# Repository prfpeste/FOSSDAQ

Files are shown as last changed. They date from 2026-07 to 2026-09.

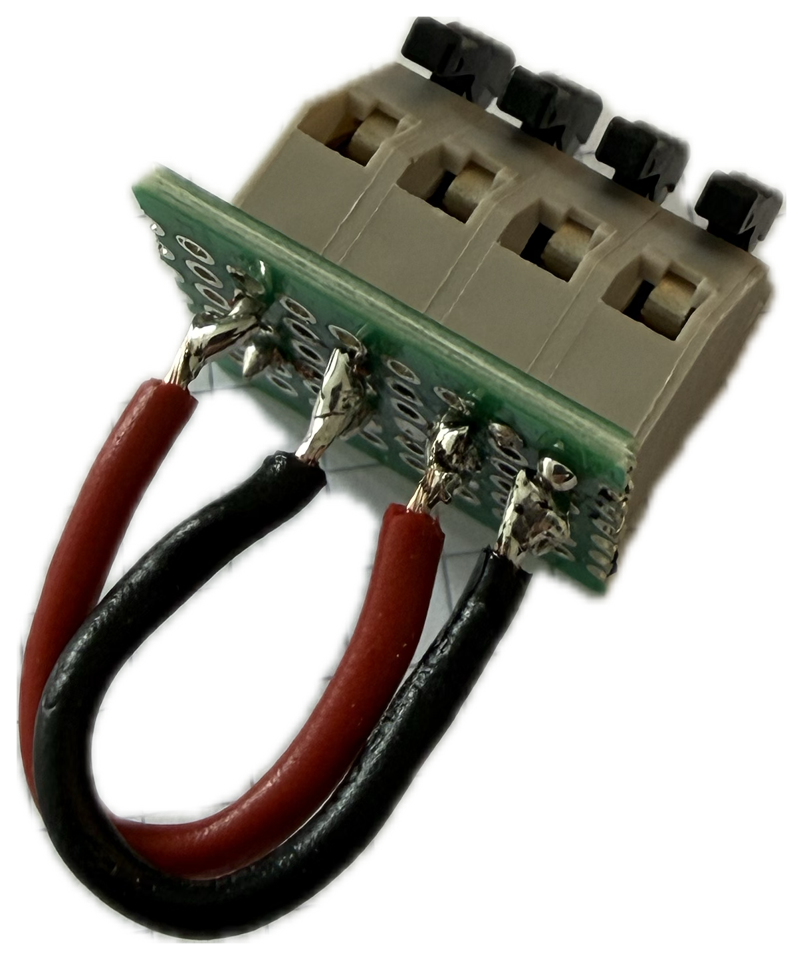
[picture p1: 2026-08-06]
modules/ai-8x-0to3v3/images/bus-terminal-solder-side.png

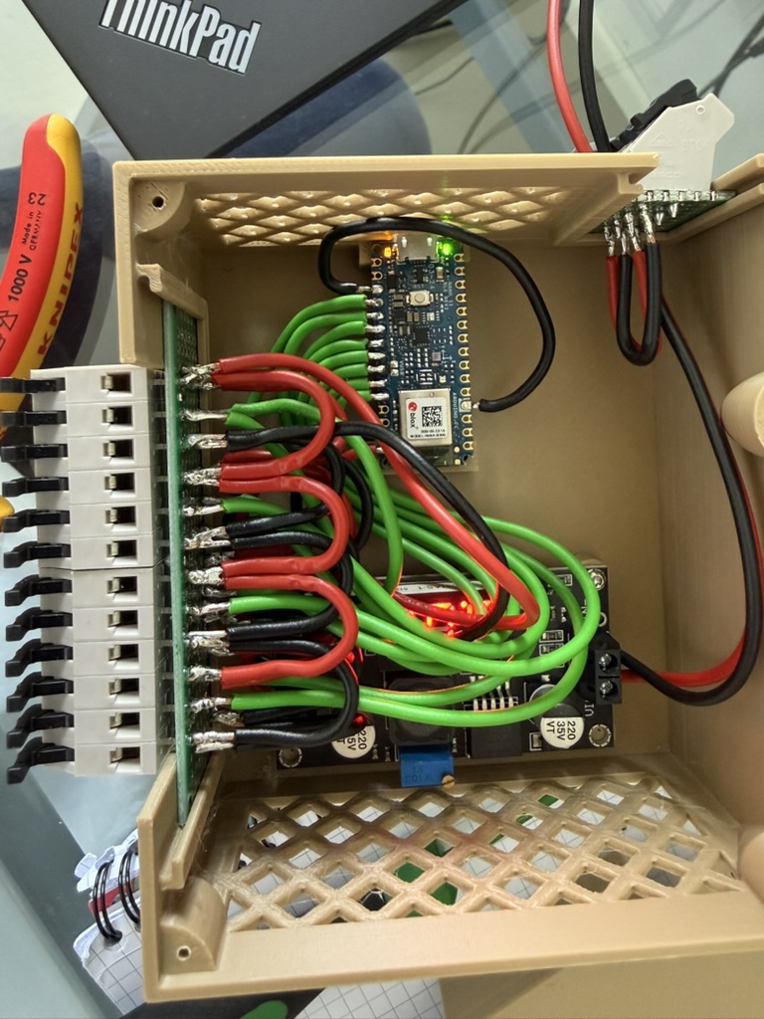
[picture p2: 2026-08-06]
modules/ai-8x-0to3v3/images/assembled-open-top.jpeg

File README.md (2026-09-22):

# FOSSDAQ
Free and Open Source Software (and hardware) for Data Acquisition 

## Project aim

The system was deliberately not designed as a fully industrialised measurement system, but rather as an easily replicable, open and cost-effective platform for use in teaching and laboratories. The focus is on low material costs, the use of readily available standard components, an easily comprehensible circuit topology, and the ability for students to assemble and adapt modules themselves, and to replace them with minimal effort in the event of a fault. Additional measures to increase robustness, EMC immunity or comprehensive fault protection were therefore only taken into account to the extent that they are necessary for the intended use in supervised laboratory environments. For applications in harsh industrial environments or with increased requirements for reliability and immunity to interference, more extensive protection and interface circuitry is required.

## Repository structure

The FOSSDAQ repository is organised by purpose and module:

- `README.md`  
  Entry point to the project: overview, goals, modules, and links.

- `LICENSE-*`  
  License files for hardware, software, and documentation.

- `docs/`  
  System-level documentation, background information, contribution guidelines, and general design notes that are not tied to a single module.

- `common/`  
  Shared specifications and resources used across multiple modules, e.g. power bus concept, mechanical interface, naming conventions, and templates.

- `modules/`  
  All hardware modules of the FOSSDAQ system.  
  Each subdirectory (e.g. `pi-base/`, `ai-8x-0to3v3/`) contains everything needed for that module:
  - `hardware/` – CAD, KiCad, manufacturing files  
  - `firmware/` – module-specific microcontroller code  
  - `docs/` – build and test notes  
  - `bom/` – parts list  
  - `images/` – photos and renders  

- `software/`  
  System-level software components and tooling.

  - `software/nodered/`  
    Node-RED based control and visualisation:
    - `README.md` – how to install and use the flows with FOSSDAQ  
    - `flows/` – exported Node-RED flows  
    - `nodes/` – custom nodes or subflows (if any)  
    - `examples/` – example setups for specific modules

## Contributors

FOSSDAQ is developed as an open modular measurement system in the context of student projects and teaching.

#### Project lead and supervision
- Prof. Dr. Peter Stein (HTWG Konstanz - Maschinenbau)

#### Core contributors
- Jürgen Altemeier (HTWG Konstanz - Maschinenbau - basic concept and first modules - 2026)
- Patrick Uitz (HTWG Konstanz - Maschinenbau - basic concept and first modules - 2026)

#### Further module contributors
- To be added as new modules are published

## Related Projects

- [FOSSTHERM](https://github.com/prfpeste/FOSSTHERM) – Free and Open Source Thermal Experiments

## License

FOSSDAQ uses different licenses for different parts of the project:

- **Hardware design files** in `hardware/` are licensed under **CERN-OHL-W-2.0**.  
  See `LICENSE-HARDWARE - CERN-OHL-W-2.0`.

- **Firmware and software** in `firmware/` and `software/` are licensed under **GPL-3.0-or-later**.  
  See `LICENSE-SOFTWARE - GPL-3.0`.

- **Documentation** in `docs/` is licensed under **CC-BY-SA-4.0**.  
  See `LICENSE-DOCS - CC-BY-SA-4.0`.

Unless explicitly stated otherwise, new files should follow the license of their parent directory.

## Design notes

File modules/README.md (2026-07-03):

## Available modules

- `pi-base` – central Raspberry Pi carrier and rail module
- `ai-8x-0to3v3` – 8-channel analog input card for 5 V sensors with 0–3.3 V output

## License

Hardware files in this module are licensed under CERN-OHL-W-2.0.  
Firmware/software is licensed under GPL-3.0.  
Documentation is licensed under CC-BY-SA-4.0.

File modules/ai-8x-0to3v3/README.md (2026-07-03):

# ai-8x-0to3v3

8-channel analog input module for the FOSSDAQ system.

This module is designed for sensors with 5 V supply and analog output signals in the range of 0–3.3 V. It is based on an Arduino Nano and communicates with the Raspberry Pi via USB.

## Status

- Development status: prototype
- Hardware version: v1.0
- Firmware status: defined separately
- Last updated: June 19, 2026

## Purpose

The `ai-8x-0to3v3` module is the first fully developed analog measurement card of the FOSSDAQ system. It is intended for simple and low-cost acquisition of analog sensor signals in educational and laboratory setups.

## Features

- 8 analog input channels
- Designed for 5 V powered sensors with 0–3.3 V signal output
- Based on Arduino Nano 33 BLE Rev2 or Arduino Nano R4
- 12-bit ADC via analog pins A0–A7
- Local 5 V generation from shared 24 V DC bus
- USB connection to Raspberry Pi for data only
- 3D-printed enclosure for TS-35 DIN rail mounting
- Spring terminal connections for sensor wiring

## Directory structure

- `hardware/` – KiCad files, CAD files, exported manufacturing files
- `firmware/` – microcontroller code for this module
- `docs/` – build notes, technical documentation, test instructions
- `bom/` – parts list for the module
- `images/` – photos and renders

**BOM** stands for **Bill of Materials** and refers to the module's parts list.

## Build and assembly

1. Print the enclosure parts.
2. Prepare the perfboard sections.
3. Assemble the 24 V input and pass-through terminal block.
4. Build the sensor terminal carrier board.
5. Solder the required connections to the Arduino Nano.
6. Connect the LM2596S power converter.
7. Install the electronics into the enclosure.
8. Connect the module to the Raspberry Pi via USB.
9. Perform the checks described in `docs/`.

## Interfaces

### Power
- Bus input: nominal 24 V DC
- Converter input range: 10–35 V DC (LM2596S module)
- Local logic/sensor supply: 5 V generated locally
- Shared system ground: yes
- Galvanic isolation: no

### Data
- Interface to host: USB 2.0
- Connector: Micro-USB-B on Arduino Nano 33 BLE Rev2
- USB used as: data path only

### Signals
- Channel count: 8
- Input pins: A0–A7
- Signal range: 0–3.3 V
- Typical sensor type: pressure or flow sensors with active 5 V supply

### Mechanics
- Mounting: TS-35 DIN rail
- Enclosure: 3D-printed
- Front connections: spring terminal blocks

## Main components

- Arduino Nano 33 BLE Rev2
- Optional alternative: Arduino Nano R4
- LM2596S DC/DC converter module
- AST 025-06 spring terminal blocks for sensor connections
- AST 025-04 spring terminal blocks for 24 V bus input/pass-through
- Double-sided perfboard
- 3D-printed enclosure parts

## Files

Important project files for this module include:
- FreeCAD files for enclosure, cover, DIN rail latch, and assembly
- KiCad schematic page for the analog input card
- BOM for components and wiring
- Build and test documentation

## Intended use and limitations

This module is intended for educational, demonstrator, and laboratory use in controlled environments. The design prioritizes simplicity, low cost, and ease of reproduction over maximum electrical robustness. The module uses a shared ground and does not include galvanic isolation. Additional protection, filtering, and EMC measures may be required for use in harsher environments or outside supervised lab settings.

## Contributors

- Jürgen Altemeier
- Patrick Uitz

## License

Hardware design files in this module are licensed under **CERN-OHL-W-2.0**.  
Firmware and software are licensed under **GPL-3.0-or-later**.  
Documentation is licensed under **CC-BY-SA-4.0**.

See the repository root license files for details.

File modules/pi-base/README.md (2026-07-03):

# pi-base

Central Raspberry Pi rail module for the FOSSDAQ system.

This module hosts the Raspberry Pi 5 as the central unit of the system, provides integration on a TS-35 DIN rail, converts the shared 24 V bus to 5 V locally, and serves as the data hub for connected measurement cards via USB.

## Status

- Development status: prototype
- Hardware version: v1.0
- Firmware/software status: external software interface defined outside this module
- Last updated: June 19, 2026

## Purpose

The `pi-base` module is the central master unit of the FOSSDAQ platform. It is intended for educational and laboratory use and provides the mechanical, electrical, and communication backbone for modular measurement cards.

## Features

- Raspberry Pi 5 based central unit
- Mounting on TS-35 DIN rail
- Local 5 V generation from shared 24 V DC bus
- 3D-printed enclosure with side cover and rail latch
- Front access to USB and Ethernet ports
- Active cooling via Raspberry Pi active cooler
- Designed for open-source reproduction and modification

## Directory structure

- `hardware/` – KiCad files, CAD files, exported manufacturing files
- `firmware/` – optional scripts or module-specific setup files
- `docs/` – build notes, technical documentation, test instructions
- `bom/` – parts list for the module
- `images/` – photos and renders

**BOM** stands for **Bill of Materials** and refers to the module's parts list.

## Build and assembly

1. Print the enclosure parts.
2. Assemble the DIN rail latch and side cover.
3. Install the Raspberry Pi 5 and active cooler.
4. Build the 24 V input and pass-through terminal assembly.
5. Connect the 24 V input to the LM2596S step-down converter.
6. Feed the generated 5 V to the Raspberry Pi.
7. Close the enclosure and perform the checks described in `docs/`.

## Interfaces

### Power
- Bus input: 24 V DC ± 5 %
- Local logic voltage: 5 V generated locally from the 24 V bus
- Shared system ground: yes

### Data
- Host system: Raspberry Pi 5
- USB used as: data connection to measurement cards
- Ethernet: available on front side
- USB power distribution to cards: not intended

### Mechanics
- Mounting: TS-35 DIN rail
- Enclosure: 3D-printed
- Cooling: active CPU cooler, enclosure ventilation openings

## Main components

- Raspberry Pi 5 (8 GB RAM recommended)
- Official Raspberry Pi active cooler
- Optional RTC battery
- LM2596S DC/DC converter module
- AST 025-04 spring terminal block for 24 V input and pass-through
- 3D-printed enclosure parts

## Files

Important project files for this module include:
- FreeCAD files for enclosure, cover, DIN rail latch, and assembly
- 3MF export files for printing
- KiCad schematic page for the 24 V supply concept
- Module-specific BOM and build documentation

## Intended use and limitations

This module is intended for supervised educational and laboratory environments. The design prioritizes simplicity, low cost, accessibility, and ease of reproduction over maximum ruggedness. Additional protection, isolation, or EMC measures may be required for use in industrial or electrically harsh environments.

## Contributors

- Jürgen Altemeier
- Patrick Uitz

## License

Hardware design files in this module are licensed under **CERN-OHL-W-2.0**.  
Firmware and software are licensed under **GPL-3.0-or-later**.  
Documentation is licensed under **CC-BY-SA-4.0**.

See the repository root license files for details.

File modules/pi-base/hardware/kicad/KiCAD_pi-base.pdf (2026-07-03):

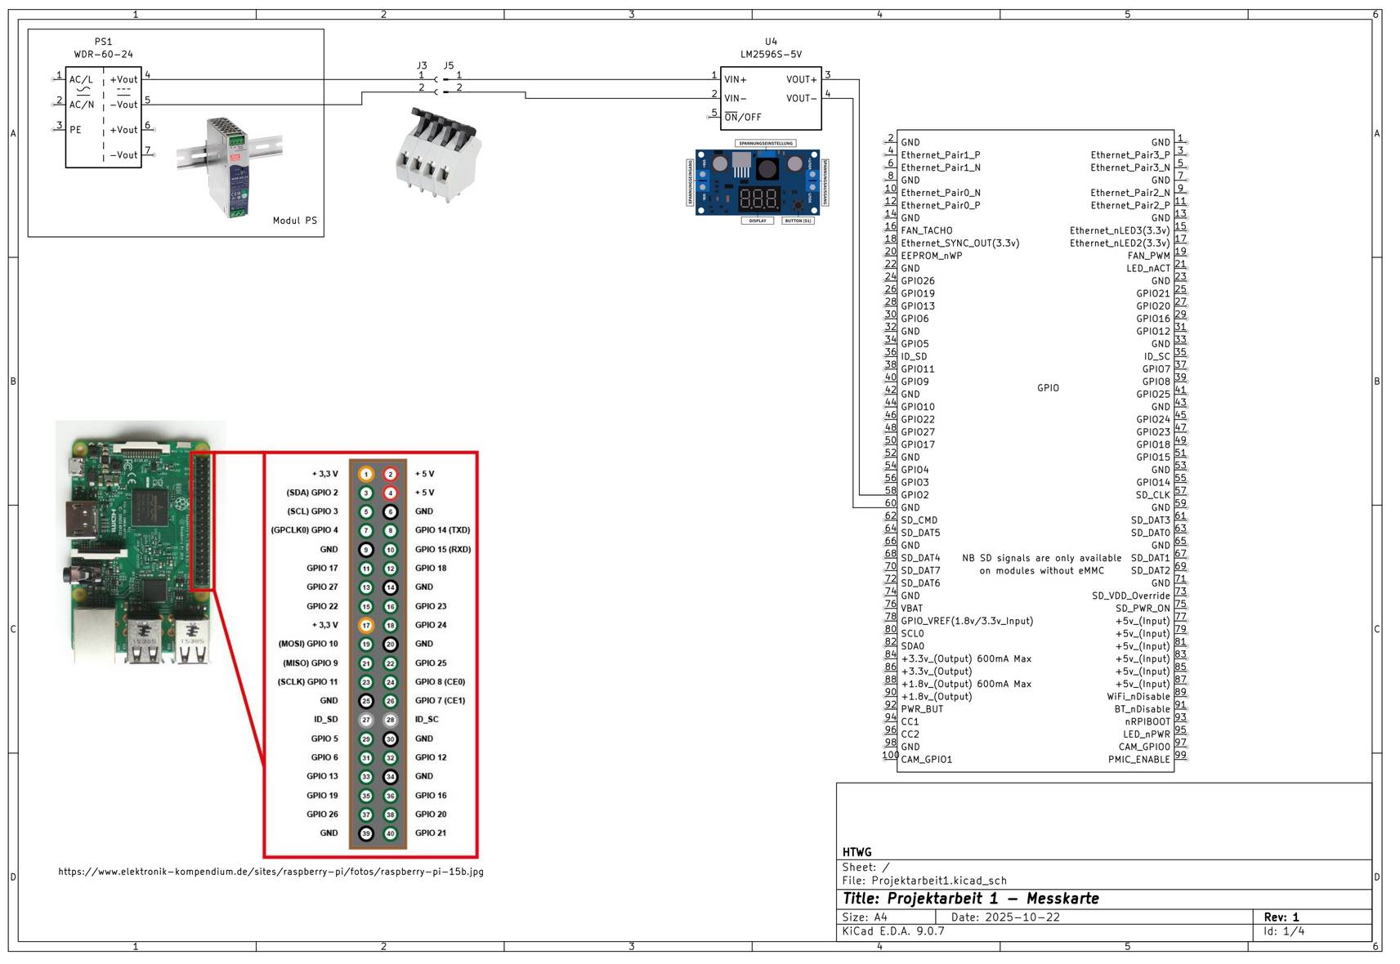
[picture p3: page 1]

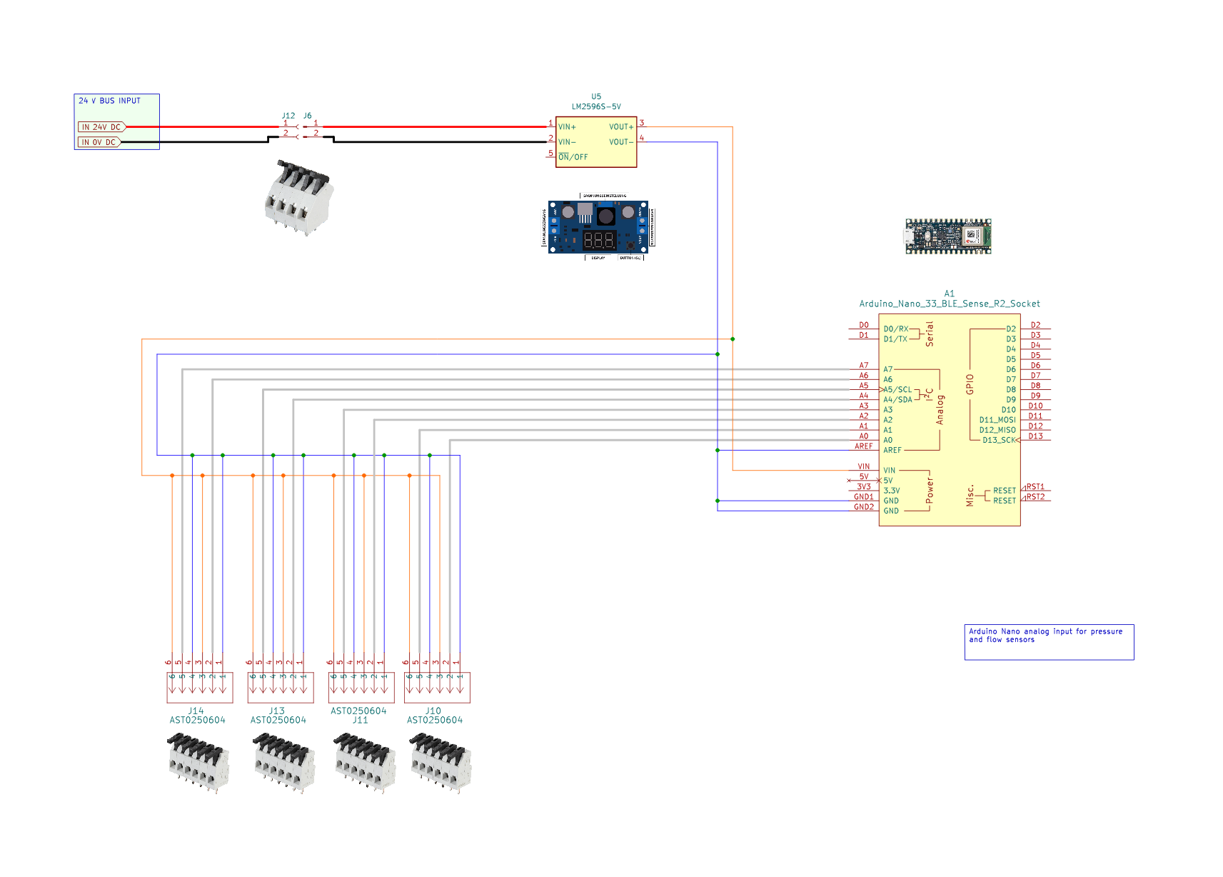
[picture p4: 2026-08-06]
modules/ai-8x-0to3v3/images/schematic-ai-8x-0to3v3.png

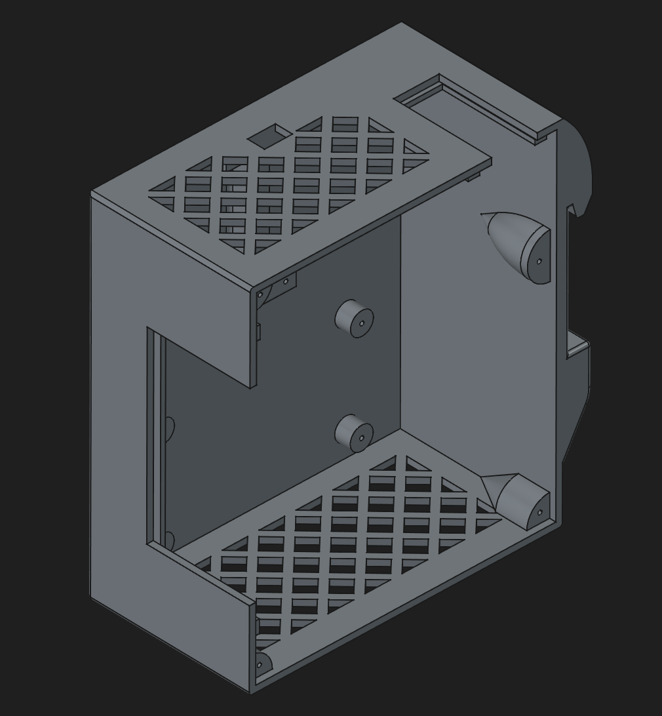
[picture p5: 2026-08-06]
modules/ai-8x-0to3v3/images/enclosure-iso-open.png

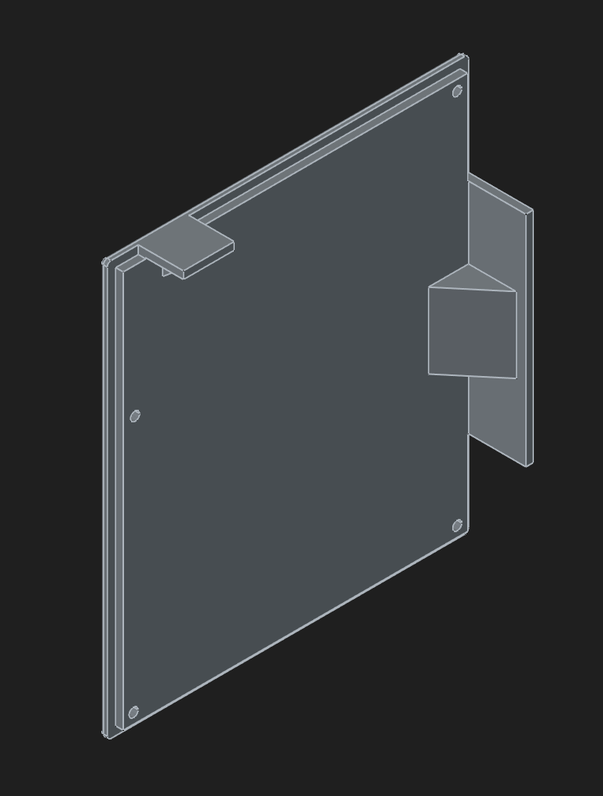
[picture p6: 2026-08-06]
modules/ai-8x-0to3v3/images/cover.png

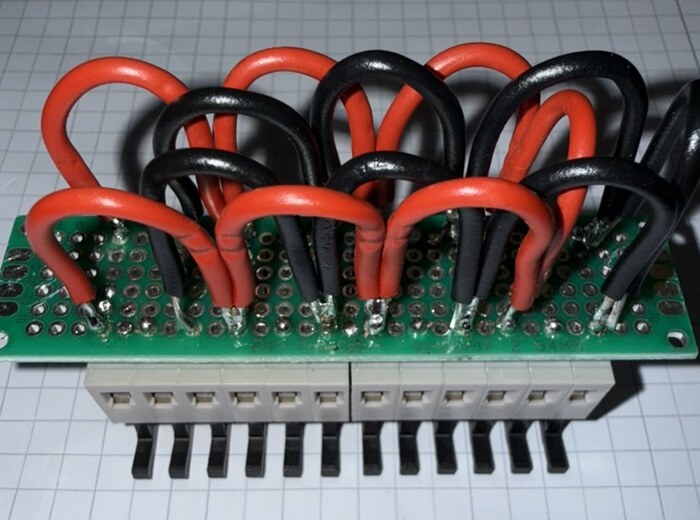
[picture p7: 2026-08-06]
modules/ai-8x-0to3v3/images/sensor-terminals-supply-rails.jpeg

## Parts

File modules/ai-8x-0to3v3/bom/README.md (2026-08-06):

# BOM
- 1 x Arduino Nano 33 BLE Rev2 - ARD NANO 33BLE2
- 2 x Breadboard (perfboard), double-sided, 80 x 20 mm - LR-DS-28 (1x sensor terminal carrier, 1x strip for the 24 V bus terminal)
- 1 x DC/DC step-down converter LM2596S with display (Joy-IT) - DEBO DCDC DOWN 5
- 4 x Spring loaded terminal, 6-pin, 5 mm pin spacing - AST 025-06 (sensor terminals)
- 1 x Spring loaded terminal, 4-pin, 5 mm pin spacing - AST 025-04 (24 V bus input + pass-through)
- 1 x USB-A to Micro-USB-B data cable, 1 m (USB-C cable for the Nano R4)
- approx. 1 m stranded wire H05V-K 1 x 0.75 mm², red (+24 V / +5 V)
- approx. 1 m stranded wire H05V-K 1 x 0.75 mm², black (0 V)
- approx. 2 m stranded wire H05V-K 1 x 0.75 mm², green (sensor signals A0-A7)
- 3D printing PLA filament
- min. 15 x self-tapping Torx screws M2.3 x 6 mm (assortment set) - B0G6YNG9CW

Notes: Part designations follow the supplier product titles, so
they can be found directly together with the order codes. Wire colors are
freely selectable - recommended: red for +24 V/+5 V, black for 0 V and
green for signal wires (consistent across the whole system).

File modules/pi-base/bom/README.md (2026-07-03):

#BOM
- 1 x Raspberry Pi 5B
- 1 x Lüfter für Raspberry Pi 5 - RASP ACTIVE COOL
- 1 x RTC Batterie - RASP RTC BAT
- 1 x Lochrasterplatine 80 x 20 mm - LR-DS-28
- 1 x DC/DC converters - DEBO DCDC DOWN 5
- 1 x Federkraftklemme - AST 025-04 (4-pol., RM 5 mm)
- 3D Druck PLA Filament
- 12 x Schrauben M2,3 x 6 mm selbstschneidend (Torx-Set) -B0G6YNG9CW

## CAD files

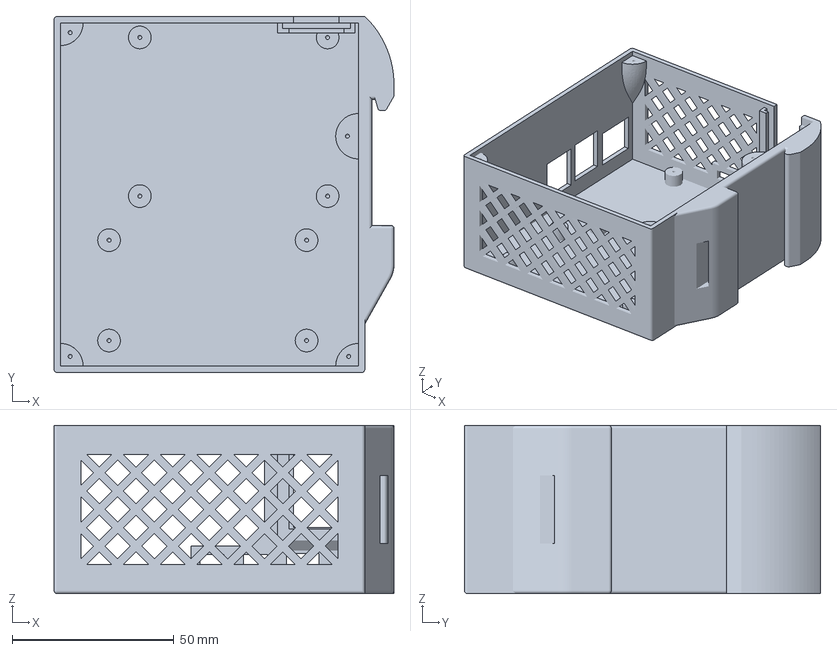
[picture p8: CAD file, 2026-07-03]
modules/pi-base/hardware/cad/End_Gehäuse+Slate-Assembly.3mf
105.0 x 110.0 x 52.0 mm

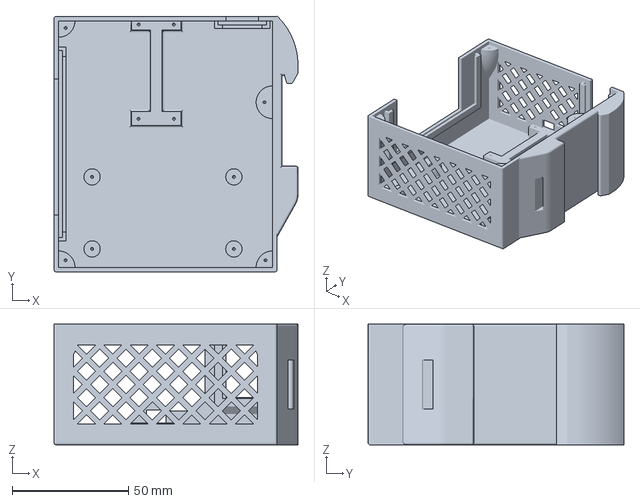
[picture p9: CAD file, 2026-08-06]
modules/ai-8x-0to3v3/hardware/cad/AI-Gehaeuse+Slate-Assembly.3mf
105.0 x 110.1 x 52.0 mm

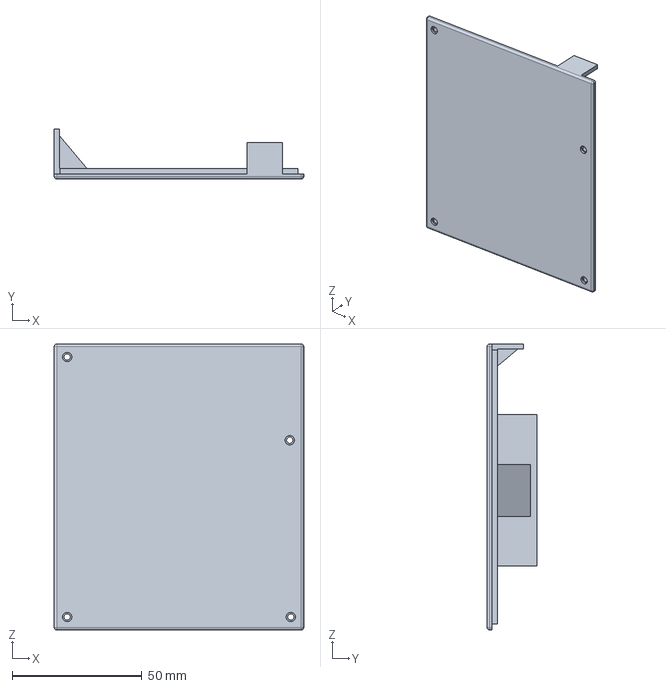
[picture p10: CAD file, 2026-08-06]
modules/ai-8x-0to3v3/hardware/cad/AI-Deckel_v2.FCStd
96.0 x 19.3 x 110.0 mm

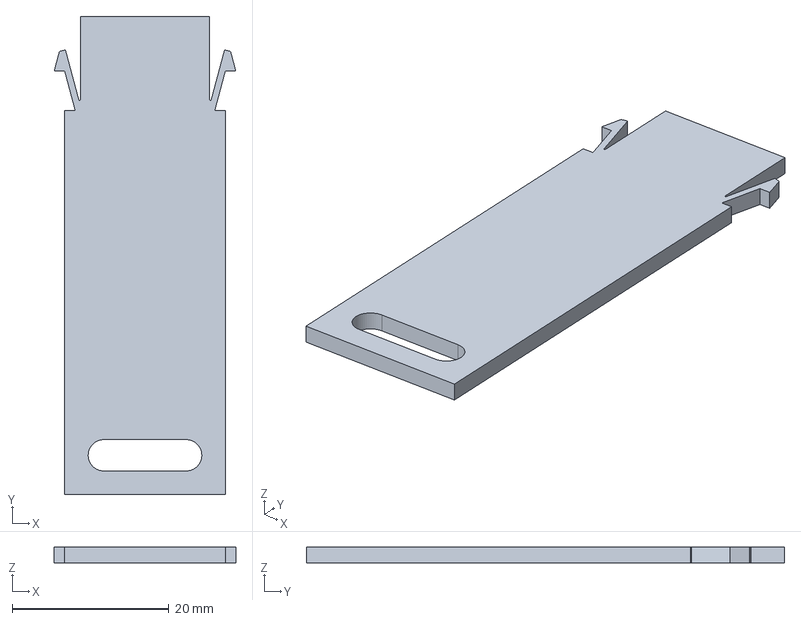
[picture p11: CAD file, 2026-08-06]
modules/ai-8x-0to3v3/hardware/cad/AI-Stift.FCStd
23.2 x 61.0 x 2.00 mm

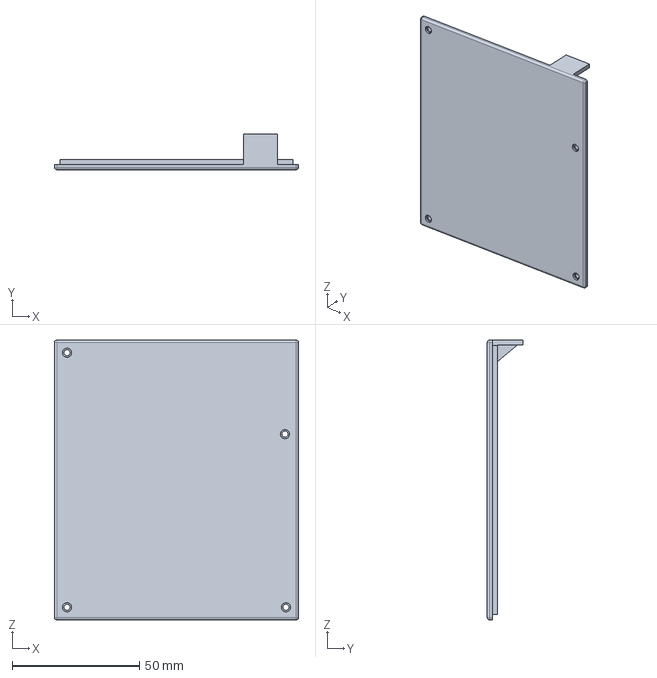
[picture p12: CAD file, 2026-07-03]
modules/pi-base/hardware/cad/End_Deckel.FCStd
96.0 x 14.0 x 110.0 mm

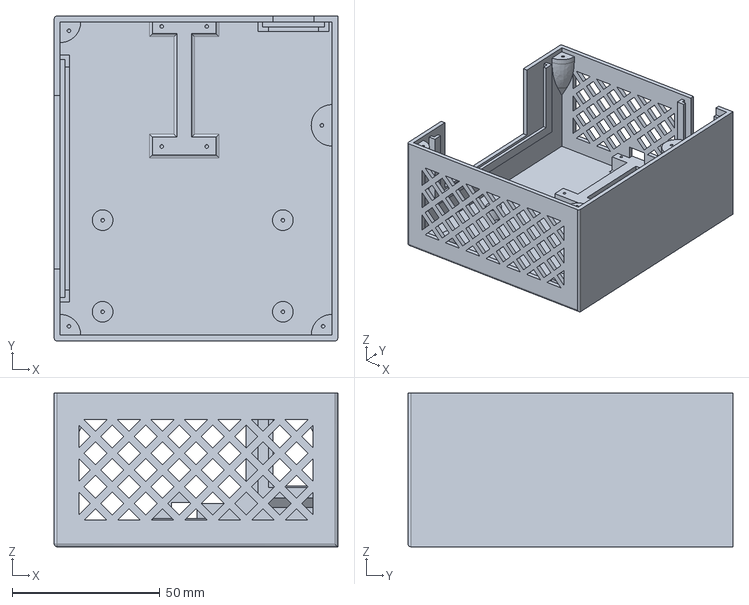
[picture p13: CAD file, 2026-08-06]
modules/ai-8x-0to3v3/hardware/cad/AI-Gehaeuse.FCStd
96.0 x 110.0 x 52.0 mm

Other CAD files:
modules/pi-base/hardware/cad/End_Deckel-Body.3mf
modules/ai-8x-0to3v3/hardware/cad/AI-Deckel_v2-Body.3mf
modules/pi-base/hardware/cad/End_Gehäuse+Slate.FCStd
modules/pi-base/hardware/cad/End_Stift.FCStd
modules/ai-8x-0to3v3/hardware/cad/AI-Stift-Body.3mf
modules/pi-base/hardware/cad/End_Stift-Body.3mf
modules/ai-8x-0to3v3/hardware/cad/AI-Deckel_v2-Body.stl
modules/ai-8x-0to3v3/hardware/cad/AI-Gehaeuse+Slate-Assembly.stl
modules/ai-8x-0to3v3/hardware/cad/AI-Stift-Body.stl

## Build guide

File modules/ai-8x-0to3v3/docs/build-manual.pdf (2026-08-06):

## FOSSDAQ

# ai-8x-0to3v3

### Build Manual 8-channel analog input card (0–3.3 V) on TS-35 DIN rail

Project: | FOSSDAQ
Module: | ai-8x-0to3v3
Authors: | Jürgen Altemeier, Patrick Uitz
Supervision: | Prof. Dr. Peter Stein, HTWG Konstanz
Hardware version: | v1.0 (July 2026)

ai-8x-0to3v3 — Build Manual | FOSSDAQ

## Contents

## 1 Basic data

The ai-8x-0to3v3 card is the first fully developed measurement module of the FOSSDAQ system. It accepts up to eight actively supplied sensors with a 0–3.3 V signal output — typical pressure or flow sensors — supplies them with stabilized 5 V and delivers the readings to the Raspberry Pi via USB.

Property | Value
Function | 8-channel analog input card for 5 V sensors with 0–3.3 V output
Controller | Arduino Nano 33 BLE Rev2 (alternative: Arduino Nano R4)
ADC | 12-bit, analog pins A0–A7
Supply | 24 V DC bus input; local 5 V via LM2596S (input range 10–35 V DC)
Sensor supply | 5 V from the local rail, up to 2 A available (a few 100 mA used)
Signal range | 0–3.3 V with the Nano 33 BLE Rev2; 0–5 V when built with the Nano R4
Data | USB to the Raspberry Pi (data only)
Mounting | TS-35 DIN rail, springy printed latch pin
Protection class | SELV; common ground with the bus, no galvanic isolation

Only sensors with 5 V supply and 0–3.3 V output

The sensors are powered with 5 V, but their signal goes directly to the analog inputs of the Nano 33 BLE Rev2. These are 3.3 V pins and not 5 V tolerant. Only use sensors whose signal output never exceeds 0–3.3 V (for example 0.5–2.5 V types). Not suitable are the common ratiometric 0.5–4.5 V sensors: their output reaches 4.5 V and would overdrive the input — they would need a voltage divider.

Variant: if the card is built with the Arduino Nano R4 instead (5 V logic, 14-bit ADC), the analog inputs accept 0–5 V — ratiometric 0.5–4.5 V sensors then connect directly, without a voltage divider.

## 2 Components

Parts needed for one card (see ../bom/ for the machine-readable list):

Qty | Part | Order code | Supplier | Remark
1 | Arduino Nano 33 BLE Rev2 | ARD NANO 33BLE2 | Reichelt | nRF52840, 3.3 V logic; alternative: Nano R4 (USB-C, 5 V logic — ac-cepts 0–5 V inputs)
2 | Breadboard/perfboard 80 × 20 mm, double-sided | LR-DS-28 | Reichelt | 1 × sensor terminal car-rier, 1 × strip for the bus terminal
4 | Spring loaded terminal AST 025-06 (6-pin) | AST 025-06 | Reichelt | sensor connections, 2 sensors per terminal
1 | Spring loaded terminal AST 025-04 (4-pin) | AST 025-04 | Reichelt | 24 V bus input + pass-through
1 | DC/DC step-down con-verter LM2596S with display | DEBO DCDC DOWN 5 | Reichelt | Joy-IT module with po-tentiometer, trim to 5.0 V before use
1 | USB-A ↔︎ Micro-USB-B data cable, 1 m | — | free choice | data link to the Pi (USB-C cable for the Nano R4)
≈ 4 m | Stranded wire H05V-K 1 × 0.75 mm² , red / black / green | — | e.g. Conrad | wire colors freely se-lectable; recommended: red +24 V/+5 V, black 0 V, green sensor signals A0–A7
≥ 15 | Screws M2.3 × 6 mm, self-tapping, Torx | ASIN B0G6YNG9CW | Amazon | cover screws, thread di-rectly into PLA; sets usually contain more anyway
— | PLA filament | — | free choice | PETG as alternative

Tools: soldering iron with fine tip, lead-free solder, fine saw for the perfboard, side cutter, wire stripper, multimeter, T6 Torx bit, scalpel.

## 3 Circuit

### 3.1 Schematic

The circuit is deliberately minimal: bus input terminal, step-down converter, Arduino and sensor terminals. KiCad sources: ../hardware/kicad/.

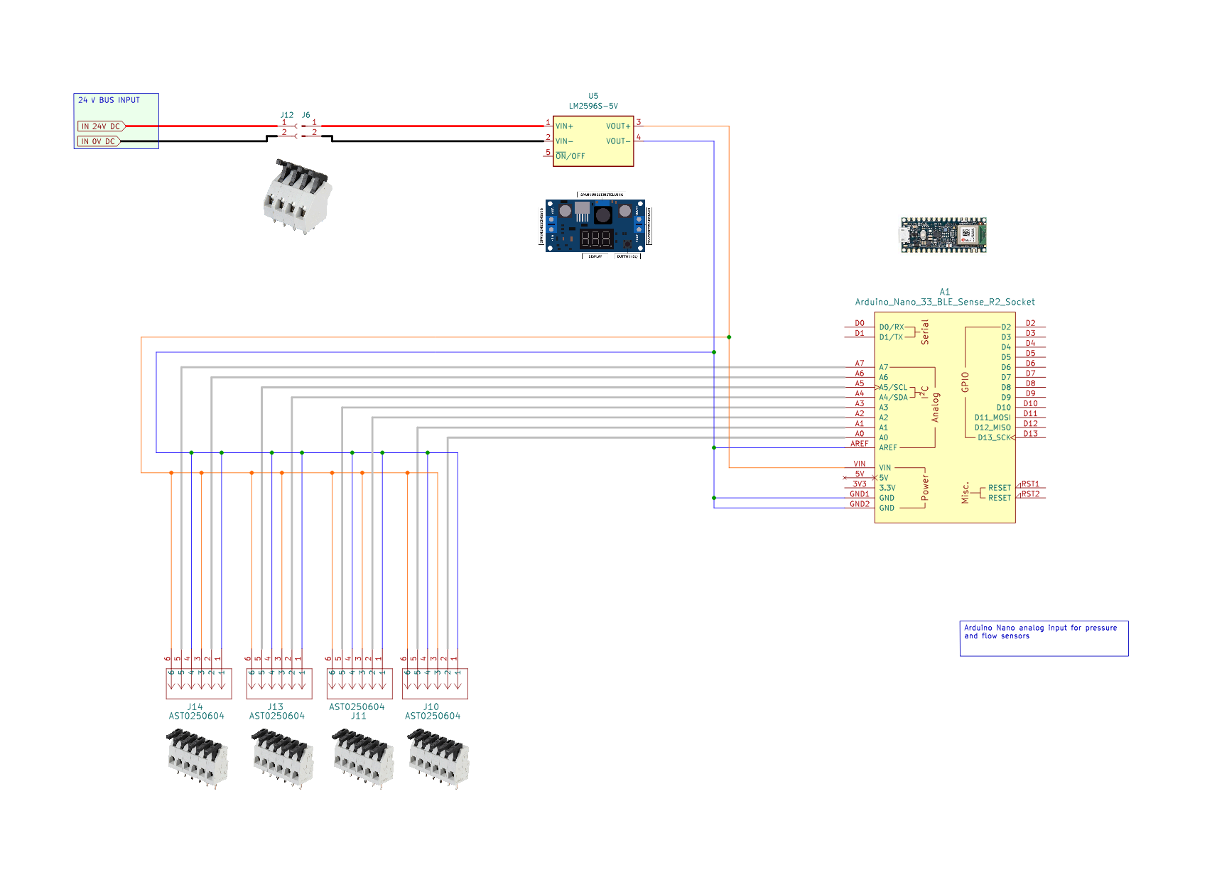
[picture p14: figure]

Figure 1: Schematic of the ai-8x-0to3v3 card.

Section | Part | Function
Input terminal | Spring loaded terminal AST 025-04 | 24 V and 0 V from the bus; the second terminal pair passes the bus on
DC/DC converter | LM2596S module | converts 24 V to a stable 5 V for Arduino and sensors
Arduino | Nano 33 BLE Rev2 | digitizes the sensor signals and sends them to the Pi via USB
Sensor terminals | four 6-pin spring loaded terminals AST 025-06 | two sensors per terminal, up to eight in total

### 3.2 Terminal pinout (two sensors per terminal)

Each 6-pole spring terminal serves two sensors with three wires each. The poles are arranged vertically, pole 1 on top, pole 6 at the bottom. +5 V and 0 V run through all terminals as common supply rails; only the signal wire goes individually to the Arduino:

Pole | Signal | Suggested color
1 (top) | +5 V for sensor A | red
2 | signal A, 0–3.3 V → Nano | green
3 | 0 V / GND for sensor A | black
4 | +5 V for sensor B | red
5 | signal B, 0–3.3 V → Nano | green
6 (bottom) | 0 V / GND for sensor B | black

### 3.3 Current budget: are eight sensors fine?

Arduino and sensors share the 5 V output of the LM2596S, so this module is the limiting element:

Item | Value
LM2596S, 5 V output | up to 2 A continuous
Arduino Nano 33 BLE | ∼ 60 mA
Eight sensors at 10–30 mA each | ≈ 80–240 mA
Total | ≈ 140–300 mA

The total load of roughly 140–300 mA is far below the 2 A of the module. Eight sensors are no problem — plenty of reserve remains. Only power-hungry sensors drawing several 100 mA each would approach the limit.

## 4 Enclosure

The enclosure follows the same principle as the pi-base module: a main body with integrated DIN-rail recess and latch pin, a screwed side cover and a slim form factor for row mounting.

Part | FreeCAD file | Function
Main body | AI-Gehaeuse+Slate.FCStd | holds the carrier board with terminals and the Arduino; DIN-rail recess on the back
Cover | AI-Deckel_v2.FCStd | side cover, screwed on
Latch pin | AI-Stift.FCStd | springy pin that locks the enclosure onto the DIN rail

Ready-to-print files (3MF and STL) are in ../hardware/print/; the editable FreeCAD sources

are in ../hardware/cad/.

### 4.1 Main body

The main body holds the carrier board with the terminals and the Arduino in a slide-in slot. Ventilation grids sit on top and bottom.

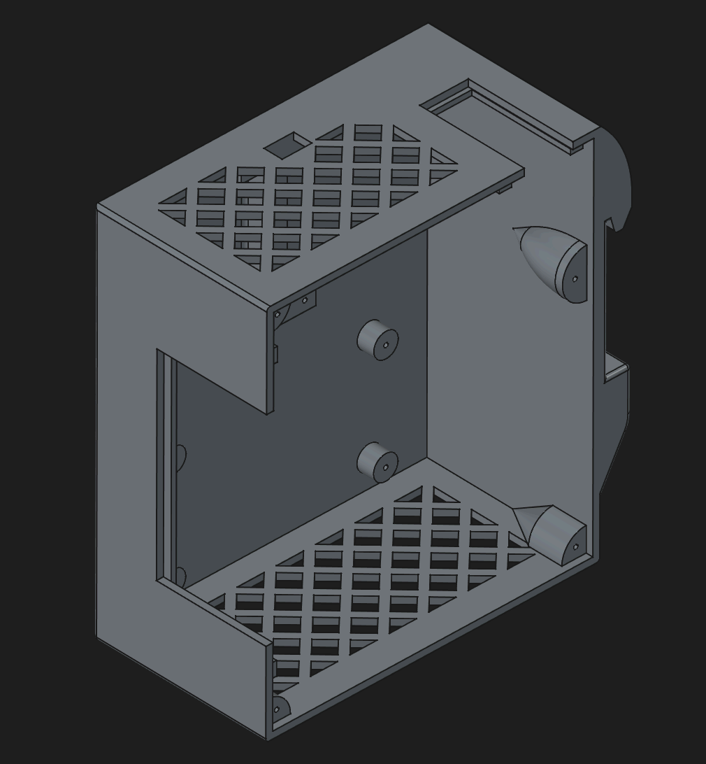
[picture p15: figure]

Figure 2: ai-8x-0to3v3 main body, open.

### 4.2 Cover

The cover closes the enclosure on the side and is fixed with four screws.

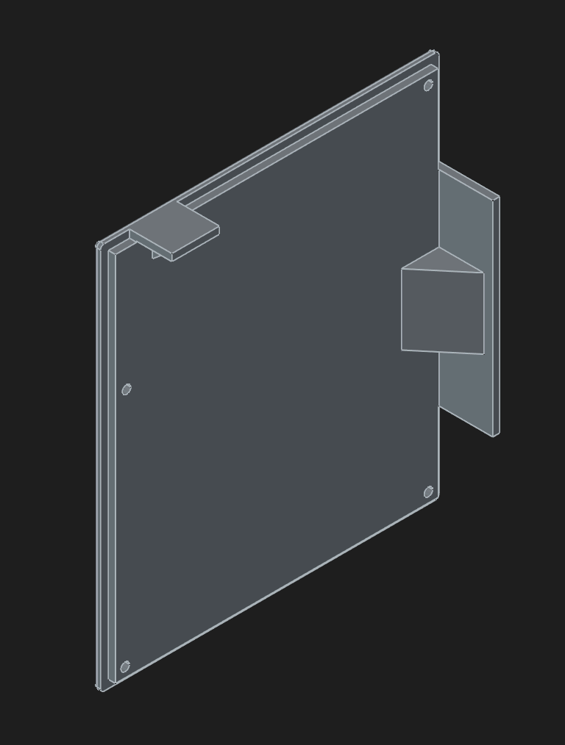
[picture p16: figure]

Figure 3: Side cover of the ai-8x-0to3v3 enclosure.

### 4.3 DIN-rail latch pin

The pin is identical in design to the pi-base pin: a separately printed springy element. Pushing the enclosure onto the rail makes it snap in; to release it, pull the pin back with a flat screwdriver.

## 5 3D printing

The print process is identical to the pi-base module.

Parameter | Value
Filament | PLA (matte), alternatively PETG
Nozzle / bed (PLA) | 210 °C / 60 °C
Supports | not required
Attention | thin walls of the slide-in slot — check the first layer carefully

## 6 24 V bus terminal assembly

The 24 V feed sits on its own narrow board strip, cut from an 80 × 20 mm perfboard (2.54 mm pitch). The bus terminal can thus be populated independently and then slid into the guide of the enclosure.

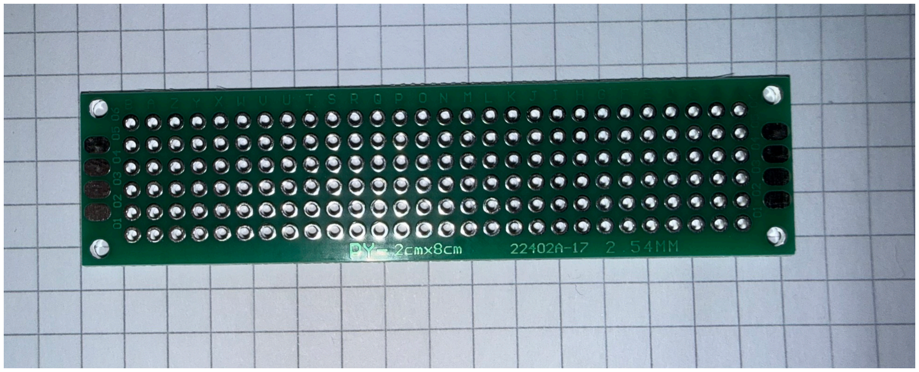
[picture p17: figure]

Figure 4: Double-sided 80 × 20 mm perfboard, raw.
1. Cut the strip. Saw the marked narrow strip off the perfboard along a hole row and deburr the cut edge.
2. Mount and solder the 4-pole terminal. Place the AST 025-04 on the strip and solder it. Bridge +24 V and 0 V with one red and one black wire jumper to the second terminal pair, so the next card can be fed from the same bus.
3. Slide it in. Slide the finished terminal carrier into the side guide of the enclosure.

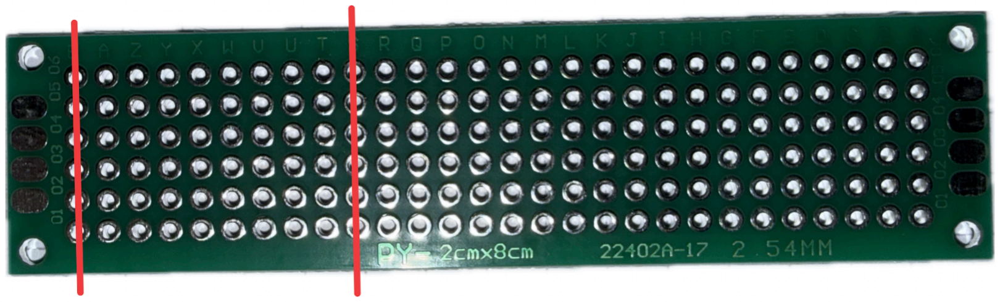
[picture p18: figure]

Figure 5: Cut line (red): strip for the 24 V bus terminal.

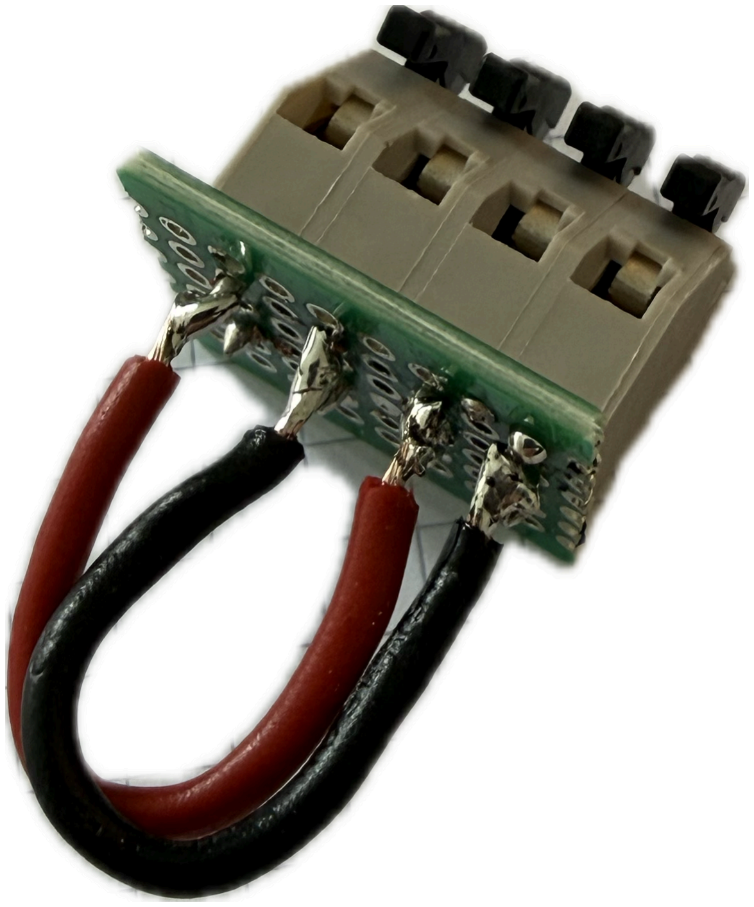
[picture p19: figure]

Figure 6: Soldered 4-pole bus terminal AST 025-04 with the pass-through bridges: +24 V in red, 0 V in black.

## 7 Sensor terminal carrier board

Each card uses a single double-sided 80 × 20 mm perfboard (2.54 mm pitch), cut to the enclosure’s inner dimension. It carries only the four 6-pole spring terminals for the sensors. All wiring and bridging is done from the rear side.

Leave a 2 mm gap between terminals and board

The terminals are not soldered flush onto the board but with a gap of about 2 mm. The enclosure wall grips into this gap when the board is slid in: the carrier board sits behind the wall while the terminals protrude in front of it. Without the gap the board cannot be inserted.

1. Set the terminals with a 2 mm gap. Place the four 6-pole terminals so that a gap of about 2 mm remains between terminal body and board, then solder from the rear. Poles are vertical, pole 1 on top, pole 6 at the bottom; each terminal serves two sensors according to the pinout table above.
2. Bridge the supply rails. On the rear side, connect the +5 V rail (red) and the 0 V rail (black) across all terminals with short wire bridges, so every sensor sees the same supply. Only the signal poles stay individual.
3. Prepare the signal wires. Cut the eight green signal wires to length for the later connection to A0–A7 of the Nano.

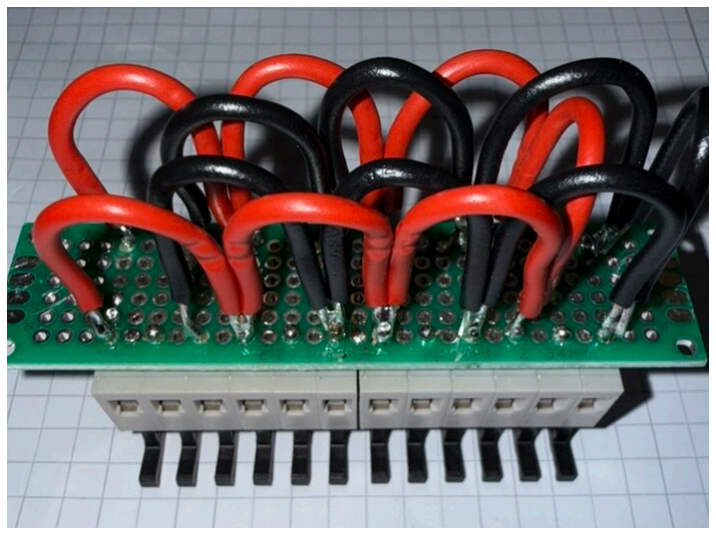
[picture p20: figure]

Figure 7: Rear of the sensor terminals with the bridged supply rails: +5 V in red, 0 V in black.

## 8 Soldering the Arduino Nano

The Arduino Nano is soldered directly via its pin headers. The relevant pins:

Arduino pin | Signal | Connected to
VIN | +5 V from DC/DC | 5 V rail from the LM2596S output
GND | ground | common 0 V
AREF | analog reference | soldered to the common 0 V as reference potential
A0–A7 | analog inputs | signals of the eight sensors, 0–3.3 V
5 V output pin | not used | sensors are fed directly from the 5 V rail

## 9 Mechanical assembly

With the 24 V terminal and the carrier board populated and the Nano wired, everything comes together in the enclosure:

### 1. Deburr the printed parts. Remove sharp edges in the slide-in slot and at the terminal

cut-outs with a scalpel.

### 2. Install the DC/DC converter and trim it to 5.0 V. Mount the LM2596S module on a socket

strip so the trim potentiometer stays accessible. Connect its input to +24 V and 0 V of the bus terminal. Before connecting the Nano: apply 24 V, trim the output to exactly 5.0 V with a multimeter, then switch the 24 V off. Continuity check: no short 24 V → 0 V and 5 V → 0 V.
3. Connect the Nano. Solder the 5 V rail to VIN and GND to the common ground.
4. Slide in the carrier board. Push the populated carrier board into the slot until it sits flush; the enclosure wall grips into the 2 mm gap between board and terminals.
5. Route the wires. Lead the eight green signal wires from the terminals to A0–A7 and route the +5 V and 0 V rails to the Nano. Keep the runs short and tidy.

### 6. Screw on the cover and insert the pin. Fix the cover with four M2.3 screws — do not

overtighten, PLA cracks easily. Insert the latch pin with its spring tab pointing up.
7. Check terminals and USB. Test the spring travel of all terminals, plug in the USB cable to the Pi and check its fit.

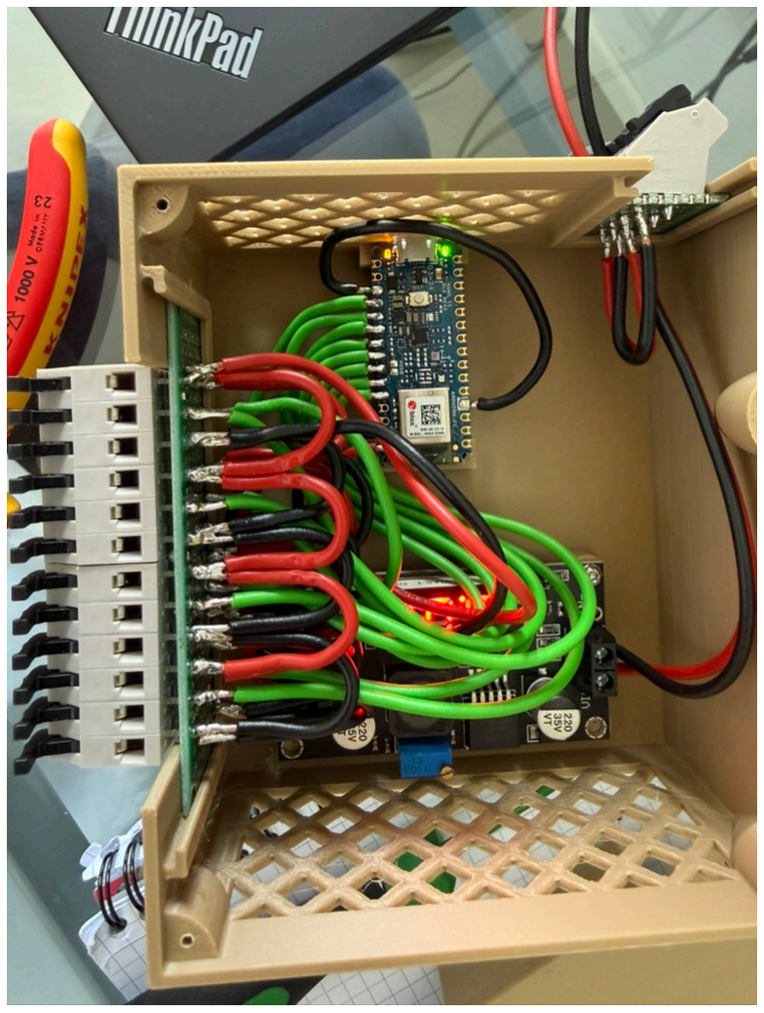
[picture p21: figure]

Figure 8: Fully wired card in the open enclosure: carrier board with sensor terminals, signal wires to the Arduino, LM2596S module.

## 10 Checks before commissioning

Firmware and Pi-side software are defined by the project supervision. Before handover, check the hardware:
1. Visual inspection of all solder joints — clean, shiny joints, no cold joints or bridges; check the orientation of polarized parts and the fit of the Arduino.

### 2. Continuity check. No short between +24 V and 0 V, and none on the 5 V rail after the

DC/DC converter.

### 3. Current-limited 24 V bench supply. Connect the card without the Arduino and watch the

current: it must settle at a stable low value. If the current limit trips immediately, there is a short.

### 4. Measure and trim the 5 V output to 5.00 V, then secure the potentiometer with a drop

of threadlocker.

### 5. Mechanical checks. Enclosure snaps onto a 35 mm DIN rail and releases again; spring

terminals hold a 1.0 mm²
test wire and release it cleanly.

## 11 Finished module

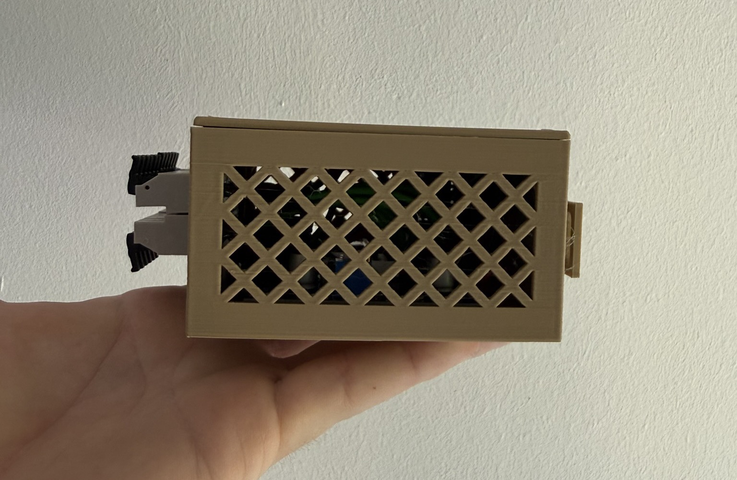
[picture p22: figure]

Figure 9: Bottom view with ventilation grid and terminals.

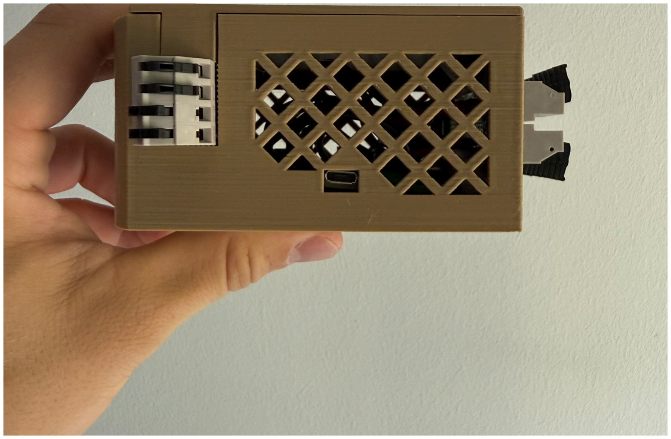
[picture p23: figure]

Figure 10: Top view with the 24 V bus terminal, the sensor terminals and the Micro-USB-B socket.

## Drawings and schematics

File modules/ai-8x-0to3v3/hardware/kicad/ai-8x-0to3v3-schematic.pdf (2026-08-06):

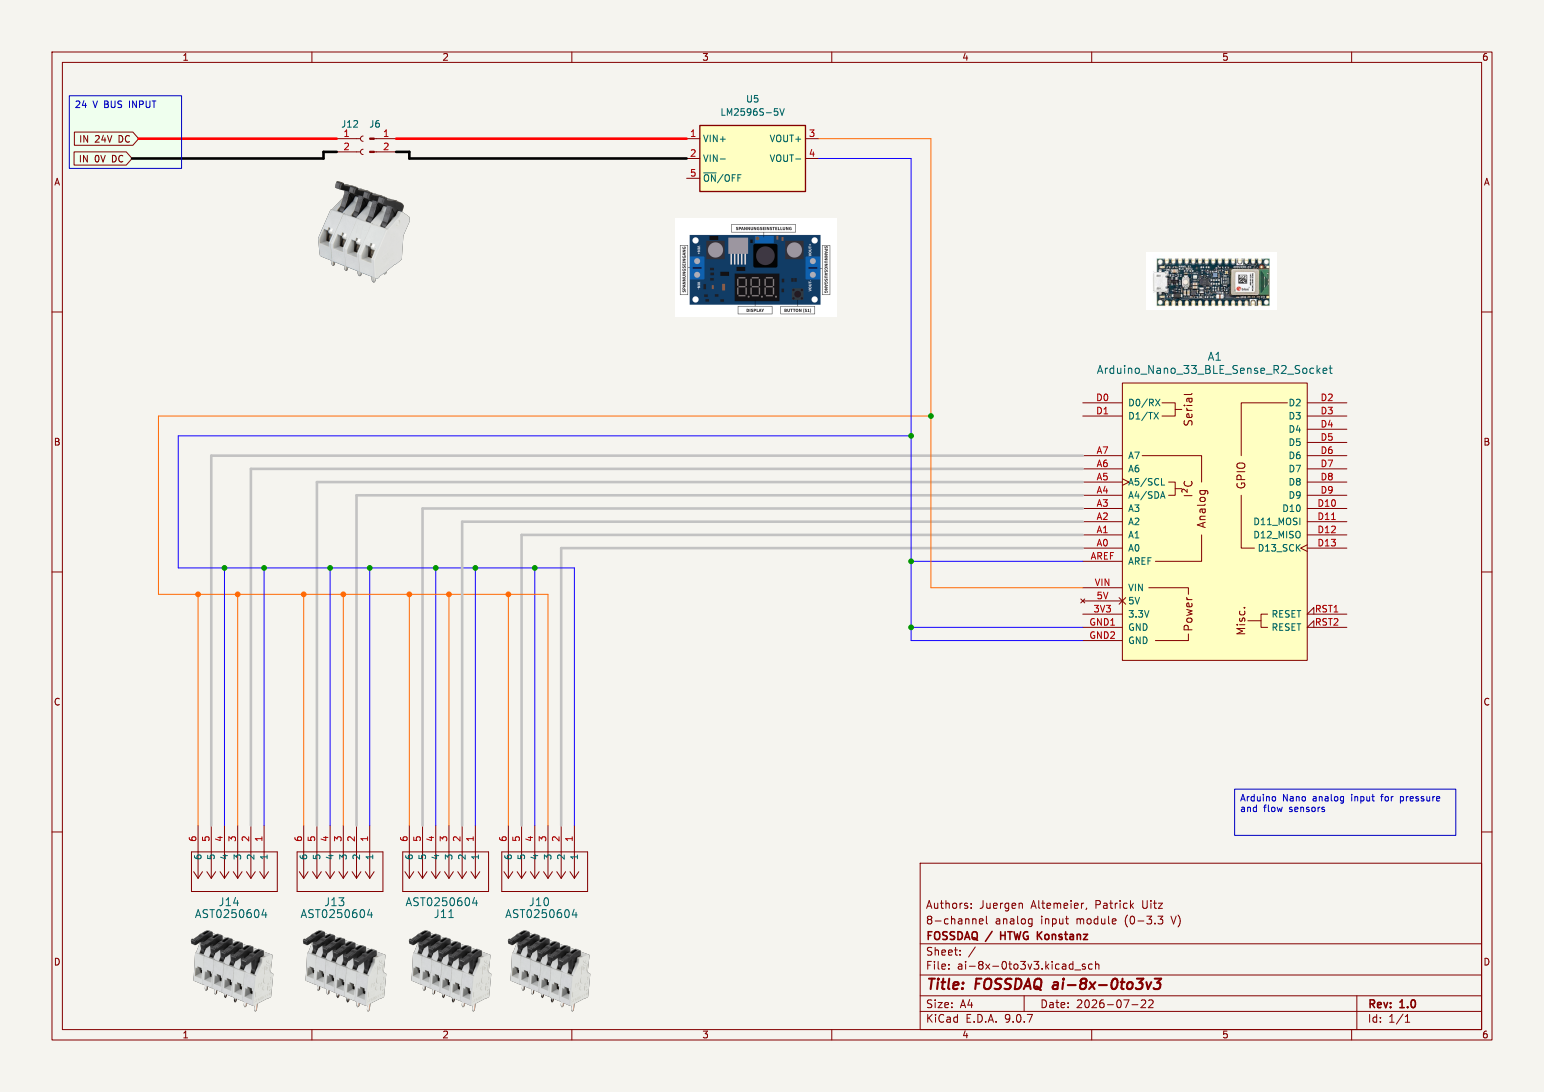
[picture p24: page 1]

6 J14 AST0250604 Serial þÿI²C Power Analog GPIO Misc. D0/RX D0 D1/TX D1 A7 A7 A6 A6 A5/SCL A5 A4/SDA A4 A3 A3 A2 A2 A1 A1 A0 A0 AREF AREF VIN VIN

Arduino Nano analog input for pressure
and flow sensors

Id: 1/1 Title: FOSSDAQ ai-8x-0to3v3

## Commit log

2026-08-06 Add README for KiCad files in ai-8x-0to3v3
    Added a README file with details about KiCad files for the ai-8x-0to3v3 project.
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2026-08-13 Create setup guide for Raspberry Pi installation
    Added comprehensive setup guide for Raspberry Pi installation, covering prerequisites, installation steps, and troubleshooting tips.
2026-08-13 Revise Raspberry Pi setup documentation
    Updated the installation guide for setting up a Raspberry Pi with Ubuntu, detailing requirements, installation steps, and troubleshooting.
2026-08-13 Revise installation guide for Raspberry Pi OS setup
    Updated installation guide for clarity and added details about the setup process, including new commands and Wi-Fi interface detection.
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2026-08-19 Add guide for connecting Raspberry Pi with Arduino
    This document provides a step-by-step guide on connecting a Raspberry Pi running Node-RED with an Arduino, including flashing the Arduino, retrieving its Serial ID, and integrating it into Node-RED.
2026-08-19 Enhance Arduino connection guide with detailed steps
    Updated instructions for connecting a new Arduino with detailed steps.
2026-08-19 Improve clarity in Arduino connection documentation
    Reworded several steps for clarity and consistency in the documentation.
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2026-08-25 Enhance README.md with setup details and instructions
    Expanded README.md to provide detailed information about the FOSSDAQ Raspberry Pi setup, including directory structure, file purposes, and instructions for adding new Arduino types and modifying conf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
2026-08-25 Update README.md with detailed node and file information
    Expanded documentation for the Custom-Nodes package, detailing node functionalities, file purposes, and instructions for adding new Arduino/board types.
2026-08-25 Enhance setup documentation for Raspberry PI
    Added additional setup instructions for Raspberry PI.
2026-08-25 Fix comment formatting in 99-arduino.rules
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2026-08-26 Enhance fossdaq-config with actuator settings
    Added new actuator configurations for PWM and AO outputs with settings for multiple outputs.
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2026-09-05 Add sensor configuration for ai-8x-0to3v3
    Added a new sensor configuration for 'ai-8x-0to3v3' with multiple sensor channels.
2026-09-05 Add do-PWM-1to6x firmware implementation
    This file contains the complete implementation of the do-PWM-1to6x firmware for Arduino, including initialization, control, and measurement functions.
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2026-09-05 Update known IDs in find_arduino.sh
    Removed test ID and added new sensor ID to known IDs list.
2026-09-05 Enhance readme with Arduino PWM control details
    Added detailed documentation for Arduino PWM control script, including installation instructions, functionality overview, initialization process, and key functions.
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2026-09-05 Create README.md for Arduino ao-1to3-x-0to10V script
    Added README.md for Arduino script detailing installation, functionality, initialization process, and key functions.
2026-09-05 Enhance README with installation and functionality details
    Added detailed documentation for Arduino script functionality, initialization process, and key functions.
2026-09-05 Revise installation details in README.md
    Updated installation details to reference the current setup guide.
2026-09-05 Revise Arduino connection instructions and integration steps
    Updated the steps for retrieving the Arduino's identifier and integrating it into Node-RED. Clarified the baud rate setting and added details about the identifier format.
2026-09-05 Add removal instructions for FOSSDAQ
    Provide instructions for completely removing FOSSDAQ from Raspberry PI.
2026-09-05 Create usage guide for FOSSDAQ modules
    Added a comprehensive usage guide for FOSSDAQ, covering Arduino flashing, Node-RED connections, and module usage.
2026-09-07 Revise readme for do-PWM-1to6x module
    Updated the readme to provide detailed information about the do-PWM-1to6x module, including its features, build instructions, interfaces, and intended use.
2026-09-07 Update building instructions with PCB cutting details
    Added section on cutting PCBs to size.
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2026-09-07 Update building instructions for PCB cutting
    Added detailed instructions for cutting PCBs and measurements.
2026-09-07 Revise PCB cutting instructions and add symbol descriptions
    Updated instructions for cutting PCBs and added a section describing used symbols.
2026-09-07 Revise wire symbol descriptions in documentation
    Updated descriptions for wire symbols in building instructions.
2026-09-07 Enhance image descriptions for components
    Updated descriptions for transistor and mosfet images to include directional details.
2026-09-07 Update assembly instructions for PCB orientation
    Clarified assembly instructions for PCB placement.
2026-09-08 Convert images to HTML and enhance assembly instructions
    Updated image syntax to HTML format for better compatibility and added assembly instructions for jumper pins.
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2026-09-08 Fix table header alignment in BOM.md
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2026-09-08 Fix HTML tags in BOM markdown table
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2026-09-08 Fix table header formatting in BOM.md
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2026-09-08 Update wiring instructions for 24V terminal
    Clarified instructions for connecting terminal pins with wires, specifying the use of short and long wires.
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2026-09-09 Fix image syntax for kiCAD in build instructions
2026-09-09 Update building instructions for component connections
    Added instruction to keep wires short when connecting components.
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2026-09-09 Fix part quantities in BOM.md
    Updated the BOM table to correct part quantities for components.
2026-09-09 Fix HTML structure in BOM.md
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2026-09-10 Fix link formatting for Mounting Plate PCB
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2026-09-15 Correct quantity of perforated circuit board in instructions
    Updated the quantity of the perforated circuit board from 2 to 1 in the building instructions.
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2026-09-15 Update building instructions with connection details
    Added instructions for connecting all components and emphasized keeping wires short.
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2026-09-15 Replace 'command' with 'voltageInSteps' in DAC writes
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2026-09-18 Fix image source and update terminal soldering step
    Updated image reference and corrected terminal soldering step.
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2026-09-18 Fix links for printed components in instructions
    Updated links for printed components in the building instructions.
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2026-09-20 Correct DCDC converter position in building instructions
    Updated the position of the DCDC converter in the BOM and adjusted instructions accordingly.
2026-09-20 Fix typos and update BOM references in instructions
    Corrected typos in the building instructions, including 'Youll' to 'You'll' and 'Volatage' to 'Voltage'. Updated BOM positions for clarity.
2026-09-20 Fix description of insulated copper stranded wire
2026-09-20 Fix typos and update BOM positions in documentation
2026-09-20 Fix BOM.md formatting and update wire description
2026-09-20 Fix typos and update BOM positions in instructions
    Updated various sections for clarity and corrected BOM positions for components.
2026-09-20 Fix BOM.md formatting and remove redundant text
2026-09-20 Fix typos and update BOM positions in instructions
    Corrected typos and updated part positions in the building instructions.
2026-09-20 Correct terminology in BOM.md for components
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2026-09-22 Correct sketch reference and output format for ai-8x-5V
    Updated the sketch reference and output format in the building instructions.
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2026-09-22 Correct part numbers in building instructions
    Updated the number of parts for Arduino Nano R4 and USB-C cable.
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2026-09-26 Improve handling of board entry loading and saving
    Refactor loading and saving of board entries to avoid race conditions and ensure previous configurations are retained if the board entry is not loaded yet.
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2026-09-26 Enhance error handling for port disconnections
    Added error handling for pending requests when a port disconnects unexpectedly. Implemented rejectAllPending function to handle errors from the Arduino.
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
